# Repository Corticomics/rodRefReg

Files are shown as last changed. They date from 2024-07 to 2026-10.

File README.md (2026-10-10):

# Rodent Refreshment Regulator (RRR)

**A Simple Water Delivery System for Laboratory Animal Care**

<p align="center">
  RRR — Rodent Refreshment Regulator
</p>

## What is the Rodent Refreshment Regulator?

<p align="center">
  A drop of water, on time, every time. 16-channel scheduled water delivery for laboratory rodents, built on a Raspberry Pi 5.
</p>

The Rodent Refreshment Regulator (RRR) helps you automatically deliver precise amounts of water to laboratory animals on a schedule. It takes the guesswork out of water delivery and ensures your research animals receive consistent care.

**No programming knowledge needed!** The system has a simple, user-friendly interface designed for laboratory staff with any level of technical experience.

## Why Use the RRR System?

- **Consistent Care**: Delivers precise water amounts every time
- **Time-Saving**: Automates routine water delivery tasks
- **Animal Welfare**: Ensures animals receive proper hydration
- **Research Quality**: Improves consistency in experimental conditions
- **Remote Monitoring**: Sends alerts about system status

## Getting Started: Step-by-Step Guide

### 1. Setting Up Your System

If the system is already installed in your lab, skip to [Using the Application](#2-using-the-application). If you are building a new device from parts, follow the full bench-build runbook in [HARDWARE_SETUP.md](Project/docs/HARDWARE_SETUP.md) before running the software installer below.

**Requirements**: Raspberry Pi running **Raspberry Pi OS Bookworm (64-bit)** with internet access.

#### One-line install (recommended)

Open a terminal on your Raspberry Pi and run:

```bash
curl -fsSL https://raw.githubusercontent.com/Corticomics/rodRefReg/main/bootstrap.sh | bash
```

That command downloads a small bootstrap script, which installs `git`, clones the repository into `~/rodRefReg`, and then runs the full installer non-interactively. The whole process takes ~5–10 minutes on a fresh Pi (sudo password prompted once for apt).

To preview without changing anything:

```bash
curl -fsSL https://raw.githubusercontent.com/Corticomics/rodRefReg/main/bootstrap.sh | bash -s -- --dry-run
```

#### Manual install

If you'd rather audit the code before running it, or you already have the repo cloned:

```bash
git clone https://github.com/Corticomics/rodRefReg.git ~/rodRefReg
cd ~/rodRefReg
./install.sh
``` 
It will:

- Install all system and Python dependencies
- Enable I²C (via `raspi-config`) without requiring a reboot
- Compile and install the Sequent Microsystems 16-relay HAT driver
- Set up a stable `/dev/teensy_flow` symlink for the Teensy flow sensor (via udev)
- Create a desktop icon, an application-menu entry, and a systemd `--user` service for autostart
- Verify every Python import and the relay HAT CLI before exiting

**Useful installer flags** (work after `./install.sh` or after `bash -s --` in the curl form):

| Flag | Purpose |
|---|---|
| `--dry-run` | Print every action without changing anything (safe to try first) |
| `-y` / `--yes` | Non-interactive mode |
| `--only <module>` | Run a single stage, e.g. `--only 40-hardware` |
| `--skip <module>` | Skip a stage, repeatable |
| `--branch <name>` | Install from a non-`main` branch |
| `--help` | Full usage |

**After install**: log out and back in once (so the new `i2c`, `gpio`, `dialout` group memberships apply), then launch via the desktop icon or `~/.local/bin/rrr`. Reboot only if you want the `consoleblank=0` boot setting to take effect.

Logs from every install run live under `~/.local/state/rrr/install-<timestamp>.log`.

## Documentation

This README is the entry point. Topic-specific runbooks live in
[`Project/docs/`](Project/docs/); each is linked once below so this file stays the single
table of contents you need to bookmark.

| Document | When to read it |
|---|---|
| [HARDWARE_SETUP.md](Project/docs/HARDWARE_SETUP.md) | Building a device from parts: Pi, relay HAT, valves, power, common ground, tubing, wall mount. Read this first for any new install. |
| [16-RELAYS Vendor Manual (PDF)](Project/docs/16-RELAYS-UsersGuide_d5e24457-bdd9-4e16-a307-7f90bbd668bb.pdf) | Authoritative reference for the Sequent Microsystems relay HAT (jumpers, stack levels, I²C addresses). |
| [QUICK_REFERENCE.md](QUICK_REFERENCE.md) | Day-to-day operator cheatsheet (animals, schedules, cages, shortcuts). |
| [CALIBRATION_QUICK_START.md](Project/docs/CALIBRATION_QUICK_START.md) | Calibrating a valve in about 10 minutes with the in-app wizard. |
| [VALVE_CALIBRATION_GUIDE.md](Project/docs/VALVE_CALIBRATION_GUIDE.md) | Technical reference behind the calibration wizard (algorithm, schema, API). |
| [PRIMING_FEATURE_DOCUMENTATION.md](Project/docs/PRIMING_FEATURE_DOCUMENTATION.md) | Priming control architecture and safety interlocks. |
| [TOPOLOGY_VALIDATION.md](Project/docs/TOPOLOGY_VALIDATION.md) | Proving an independent (one syringe per animal) rig against the manifold rig: pre-declared criteria C1–C9, bench recipe, and the tools that grade the weighings. |
| [DEVELOPMENT.md](Project/docs/DEVELOPMENT.md) | Software architecture, modules, data flow, and dev-environment setup. |
| [DATABASE.md](Project/docs/DATABASE.md) / [DATABASE_ARCHITECTURE.md](Project/docs/DATABASE_ARCHITECTURE.md) | SQLite schema, ERD, and `DatabaseHandler` reference. |
| [STOP_AND_PARTIAL_DELIVERY.md](Project/docs/STOP_AND_PARTIAL_DELIVERY.md) | Design of v2.0.0's Stop, CLOSE ALL RELAYS availability, run history and the Animals tab's last-run column (for maintainers). |
| [MAINTENANCE.md](Project/docs/MAINTENANCE.md) | Release, versioning (SemVer for RRR), tagging, and recovery procedures. |
| [UPDATE_SYSTEM.md](Project/docs/UPDATE_SYSTEM.md) | Full design of the in-app update pipeline (bundle format, blue-green layout, boot sentinel). |
| [CLAUDE.md](CLAUDE.md) | One-page hard-rules summary for maintainers and AI assistants. |
| [STL Files](Project/docs/STL%20Files/) | 3D-printable reservoir mounts, intra-cage water collectors, pump holders. |
---

### 2. Using the Application

#### First-Time Login

1. Start the RRR application by clicking the desktop icon or running `~/.local/bin/rrr`
2. You'll see a login screen - if you don't have an account, click "Create Account" to continue
3. The main screen will appear with several tabs

#### Adding Your Animals

1. Go to the **Animals** tab
2. Click **Add Animal**
3. Enter the animal's information as requested
4. Click **Save**
5. Repeat for each animal

#### Naming Cages

1. Go to the **Cages** tab to see a visual layout of the relay board
2. Double-click any cage tile, type a custom name (e.g., "Rack A — Cage 3") and press Enter
3. Names sync automatically to the Wizard, Schedules, and Calibration views

#### Creating a Water Delivery Schedule

The **Schedule Wizard** walks you through schedule creation in 4 steps:

1. Go to the **Wizard** tab (or click **+ New Schedule** in the Schedules hub)
2. **Step 1 — Type**: Choose between:
   - **Instant Delivery**: All animals receive their volume at the same time; conflicting times are auto-queued
   - **Staggered Delivery**: The total volume is divided uniformly across the selected time window
3. **Step 2 — Animals**: Multi-select the animals/cages to include (limited by your hardware: 15 cages on the first HAT, because relay 16 is the master valve or, on an independent rig, reserved and unwired; 16 on each further HAT)
4. **Step 3 — Parameters**: Set per-animal volume, time window, and schedule name
5. **Step 4 — Review**: Confirm the configuration and click **Save Schedule**

The new schedule appears as a card in the **Schedules** hub.

#### Managing Schedules

- The **Schedules** tab is a hub that shows every schedule as a card with a search bar and multi-select for bulk delete
- Click **Edit** on any card to reopen the wizard-style editor
- Click **Info** for full schedule details

#### Starting Water Delivery

1. In the **Schedules** hub, drag a schedule card onto the **Run/Stop** drop area on the right
2. Click **Run**. In solenoid pulse mode (the default), Run refuses a schedule that waters a cage with no usable calibration measured under this device's valve topology: it shows *Valve calibration needed* with the cages to calibrate, and the schedule does not start
3. The **Execution Monitor** tab appears next to the Terminal and shows live per-cage progress
4. Monitor the terminal output or the Execution Monitor cards for real-time updates

#### Stopping the Program

1. Click **Stop** to halt water delivery
2. RRR closes every relay. If a relay HAT does not confirm, it shows **Relays Not Confirmed Off**: a valve may still be open, so disconnect the valve power supply, then check the relay HAT and its I²C connection

#### Unattended Operation

The RRR system is designed to run continuously even when you disconnect your display, keyboard, or mouse. For long-term experiments:

1. **Autostart on graphical login** — enable the user-level systemd service (do **not** run this as root):
   ```bash
   systemctl --user daemon-reload
   systemctl --user enable --now rrr.service
   ```

2. **Headless / no graphical login** — also enable user lingering so the service starts at boot:
   ```bash
   sudo loginctl enable-linger "$USER"
   ```

3. **Power management**: the installer adds `consoleblank=0` to `/boot/firmware/cmdline.txt` so the console will not blank during experiments. A reboot applies this.

4. **Status & logs**:
   ```bash
   systemctl --user status rrr.service
   journalctl --user -u rrr.service -f
   ```

5. **Stop / disable**:
   ```bash
   systemctl --user disable --now rrr.service
   ```

## Daily Use Guide

### Routine

1. **Check System Status**: Open the RRR application and verify it's running/Ran correctly
2. **Update Animal Weights**: Record new animal weights in the Animals tab
3. **Inspect Water Lines**: Check for any leaks or blockages
4. **Water Reservoir**: Ensure the water reservoir has sufficient clean water. On an independent rig (one syringe per animal), check every syringe line daily; a primed line holds about three days, so prime again (Settings → Priming) any line left idle over a long weekend

5. **Check Delivery Log**: Review the delivery history in the terminal
6. **Verify Schedules**: Confirm schedules for the next day
7. **Backup Data** (optional): Export/Import animal data if needed

## Common Questions

### What if the system isn't delivering water?

1. Check that **Run** has been clicked and the schedule started: if Run showed *Valve calibration needed* or *Cage not on this device*, calibrate the listed cages in **Settings → Calibration** (or edit the schedule) and press **Run** again
2. Verify that your time window is correct: a schedule whose end time has passed shows *Expired Schedule* and does not start; if only the start time has passed, RRR asks whether to run the rest of the window
3. Inspect the water tubes for air bubbles or blockages (make sure to prime the tubes and pumpos prior to first use)
4. Check that the water reservoir has enough water
5. Look in the Terminal tab for `[VALVE ERROR]`: the line says why that delivery stopped, most often a valve command that did not reach its relay HAT. Check the HAT (`sudo i2cdetect -y 1`); after fixing a HAT that was missing when RRR started, close and reopen RRR

### How do I know how much water each animal received?

You can watch each delivery in the Terminal tab. Every delivery is also written to the `dispensing_history` table (the delivery ledger): the dose asked for, the volume dispensed and its status. On the device, `cd ~/rrr/current/Project && ~/rrr/shared/venv/bin/python3 tools/gravimetric_check.py daily --since YYYY-MM-DD` prints each day's totals per cage.

### What if I need to change a schedule mid-experiment?

You can create a new schedule at any time. Stop the current program, create your new schedule, and start the program again with the new settings.

### How do I calibrate the system for accurate water delivery?

Go to **Settings → Calibration**. The table lists every cage, with the custom names you set in the Cages tab. Click **Calibrate** on a cage's row, or **Calibrate All Uncalibrated** to go through every cage that has no calibration yet, one marked **Invalid** (its volume per pulse or pulse width is missing, zero or invalid), or one marked **Stale** (measured under the other valve topology; one saved before v1.21.0 counts as shared manifold). Set the valve topology (**Settings → Delivery → Valve Topology**) before calibrating. For each cage the wizard:

1. Walks you through a pre-flight checklist (prime the tubing in the **Priming** sub-tab first if it holds air)
2. Fires a fixed number of pulses into a beaker at the pulse width and interval you set
3. Asks for the volume you weighed
4. Saves that cage's mL per pulse, with the valve topology it was measured under; every later delivery to the cage uses it. In solenoid pulse mode (the default), **Run** refuses a schedule that waters a cage with no calibration, an Invalid one or a Stale one

Calibrate before starting a new experiment and periodically to maintain accuracy. The **Priming** sub-tab in Settings can be used on its own any time you swap tubing, refill the reservoir or, on an independent rig, refill or replace a syringe. It is refused while a schedule or a calibration is running. Changing the valve topology restarts RRR, and Priming then shows the controls for the new topology; if RRR cannot restart itself, Priming cannot open a valve until RRR is closed and reopened.

### How do I resolve "i2c-1 not found" or other I²C errors?

The installer enables I²C automatically via `raspi-config nonint do_i2c 0`, which makes `/dev/i2c-1` (the GPIO HAT bus) appear without a reboot on every Pi 4 and Pi 5. If the relay HAT does not respond:

1. Confirm the bus is up:
   ```bash
   ls /dev/i2c-*           # /dev/i2c-1 must be in the list
   sudo i2cdetect -y 1     # the HAT should appear at its I²C address
   ```

2. If `/dev/i2c-1` is missing, re-run the hardware module of the installer (idempotent, ~5 s):
   ```bash
   cd ~/rodRefReg
   ./install.sh -y --only 40-hardware
   ```

3. If it is still missing, run the standalone helper and reboot:
   ```bash
   ~/rodRefReg/scripts/runtime/fix_i2c.sh
   sudo reboot
   ```

4. As a last resort, enable I²C interactively:
   ```bash
   sudo raspi-config       # → Interface Options → I2C → Enable
   ```

Different Raspberry Pi models expose different *internal* I²C bus numbers (Pi 5 also shows `/dev/i2c-13` and `/dev/i2c-14`), but the relay HAT always sits on bus 1.

### How can I run a Python script against the RRR install?

The application uses a virtual environment at `~/rrr/shared/venv`, and the running release lives in `~/rrr/current`. Always call that Python directly — do **not** rely on the system `python3`, which (on Bookworm) is intentionally locked down by PEP 668:

```bash
cd ~/rrr/current/Project
~/rrr/shared/venv/bin/python3 tools/gravimetric_check.py list
```

That example only reads the delivery ledger. Do **not** run `tests/test_relay_hat.py` on a plumbed rig: without arguments it switches every relay on, which opens every valve.

## Getting Help

If you need assistance with the RRR system:

1. Click the **Help** tab in the application for detailed guides
2. Use the search bar to find specific help topics
3. Contact your laboratory manager or IT support
4. For urgent issues, contact [zepaulojr2@gmail.com](mailto:zepaulojr2@gmail.com)

## Important Safety Notes

- Always monitor the system during the first few days of a new setup
- Check animals regularly to ensure they are receiving adequate hydration and to check if the hardware setup was made correctly do not leave the subjects by themselves for the first few uses to ensure correct software and hardware setup and safety 
- Keep water lines and pumps clean to prevent contamination
- Never modify the hardware without consulting technical staff

---

**Remember**: The RRR system is designed to assist with animal care, not replace regular monitoring. Always follow your institution's animal welfare guidelines and protocols.

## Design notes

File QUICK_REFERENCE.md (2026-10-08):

# Rodent Refreshment Regulator - Quick Reference Guide

This quick reference guide covers the most common tasks and troubleshooting tips for the Rodent Refreshment Regulator (RRR) system. For more detailed information, refer to the in-app Help tab.

## Common Tasks

### Animal Management

| Task | How To Do It |
|---|---|
| Add a new animal | Animals tab → Add Animal → Fill details → Save |
| Edit animal info | Animals tab → Select animal → Edit → Update details → Save |
| Update weight | Animals tab → Select animal → Edit → Enter new weight → Save |
| Remove animal | Animals tab → Select animal → Delete → Confirm |

### Schedule Management

| Task | How To Do It |
|---|---|
| Create schedule | Wizard tab (or "+ New Schedule" in Schedules hub) → Step 1–4 → Save |
| Edit schedule | Schedules tab → card menu → Edit → Update → Save |
| Delete schedule | Schedules tab → card menu → Delete (or multi-select → bulk delete) |
| Assign animals to cages | Inside the Wizard, Step 2 — multi-select from the available list |
| View schedule details | Schedules tab → card **Info** button |

### Cage Management

| Task | How To Do It |
|---|---|
| Rename a cage | Cages tab → double-click the cage tile → type the name → Enter (Esc cancels; relay 16 cannot be renamed) |
| View relay layout | Cages tab — shows the full HAT board: relay 16 is the MASTER SOLENOID on a shared-manifold rig and RESERVED (unused) on an independent rig |

### System Operations

| Task | How To Do It |
|---|---|
| Start water delivery | Drag schedule card onto Run/Stop drop area → **Run**. In solenoid pulse mode (the default), Run refuses a schedule that waters a cage with no usable calibration measured under this device's valve topology (*Valve calibration needed*): calibrate the listed cages first |
| Stop water delivery | **Stop**. If it shows *Relays Not Confirmed Off*, disconnect the valve power supply, then check the relay HAT and its I²C connection |
| Monitor a live run | Execution Monitor tab appears next to Terminal during a run |
| Test a valve | Settings → Priming → select the cage → **Open Selected**, then **Close Selected** (on a shared-manifold rig click **Open Master** first and **Close Master** after) |
| Calibrate valves | Settings → Calibration → **Calibrate** on the cage's row (or **Calibrate All Uncalibrated**) |
| Prime tubing | Settings → Priming → select cage → **Open Selected** → **Close Selected** once water flows (on a shared-manifold rig click **Open Master** first and **Close Master** after) |
| Change valve topology | Settings → Delivery → Valve Topology (logged in; refused while a schedule, priming or calibration runs). Confirm with **Restart RRR**: RRR restarts on the new topology. Log in again, then recalibrate the cages marked Stale |
| Set up notifications | Settings → General → Slack Integration → enter the Slack Bot Token and Channel ID (each is saved when you press Enter or leave the field, and is used from the next message) |

## Troubleshooting Guide

### Water Delivery Issues

| Problem | Solution |
|---|---|
| No water delivered | • Check if the schedule is running (Run may have refused it: *Valve calibration needed* lists the cages to calibrate)<br>• Ensure time window is correct<br>• Look in the Terminal tab for `[VALVE ERROR]`: the line says why the delivery stopped, most often a valve command that did not reach its relay HAT<br>• Check the water reservoir level, or on an independent rig that animal's syringe and line<br>• Verify pump connections (pump mode) |
| Uneven water delivery | • Check for air bubbles in tubing: prime the line (Settings → Priming)<br>• Solenoid rig: recalibrate that cage (Settings → Calibration → **Recalibrate** on its row)<br>• Pump mode: calibrate the pumps and run 200 test triggers to prime them |
| Leaking connections | • Check tube fittings<br>• Replace damaged tubing<br>• Ensure correct tube diameter (2mm) |

### Software Issues

| Problem | Solution |
|---|---|
| Application won't start | • Restart your Raspberry Pi<br>• Run `~/.local/bin/rrr` from a terminal to see error messages (where RRR runs as the user service: `journalctl --user -u rrr.service -n 50`) |
| Can't save settings | • Log in with a user account (not guest mode)<br>• Check file permissions |
| Slack notifications not working | • Verify internet connection<br>• Check Slack credentials<br>• Ensure channel ID is correct |

### Hardware Issues

| Problem | Solution |
|---|---|
| Relay HAT not detected | • Check physical connections and `sudo i2cdetect -y 1`<br>• Verify the stack-level jumpers<br>• After fixing it, close and reopen RRR: until then every valve delivery to a missing HAT fails with `[VALVE ERROR]` |
| `[VALVE CRITICAL] … OPEN`, *Emergency Stop Failed* or *Relays Not Confirmed Off* | • Disconnect the valve power supply first<br>• Then check the relay HAT and its I²C connection; Settings → Priming → CLOSE ALL RELAYS switches every relay off again and stops a running schedule (it does not resume: Run starts it over, so check what each animal has received first)<br>• `[VALVE OK] … closed after all` means a later close got through and that alarm is cleared |
| Pump not triggering | • Test the relay<br>• Check power connections<br>• Verify common ground connection |
| System freezes during operation | • Check for overheating<br>• Ensure power supply is adequate<br>• Reduce number of simultaneous triggers |

## Keyboard Shortcuts

| Shortcut | Action |
|---|---|
| `Ctrl+F` or `F3` | Help tab: jump to the search bar |
| `Ctrl+Tab` | Switch between tabs |
| `Esc` | Close popup dialogs; in the Help tab clear the search; in the Cages tab cancel a rename |

Run and Stop have no keyboard shortcut: use the **Run** and **Stop** buttons.

## Daily Checklist

### Morning Setup
- [ ] Check water reservoir level (on an independent rig, every animal's syringe) and refill if needed
- [ ] Inspect tubing for leaks or blockages; on an independent rig check every syringe line daily; a primed line holds about three days, so prime again any line left idle over a long weekend
- [ ] Update animal weights
- [ ] Verify schedule for the day
- [ ] Start the program

### Evening Closeout
- [ ] Review water delivery logs
- [ ] Check animal hydration status
- [ ] Clean any soiled tubing
- [ ] Prepare schedule for next day if needed

## Contact Information

For technical support, contact:
- Lab Tech: [Jose Paulo](mailto:josepaulo.pereirajun@ucalgary.ca)

For application issues, report through the Help tab in the application.

---

**Remember**: The Help tab in the application provides more detailed information on all features. Use the search function to quickly find specific topics.

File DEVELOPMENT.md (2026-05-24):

# Rodent Refreshment Regulator - Development Guide

This document provides technical information for developers who want to understand or contribute to the Rodent Refreshment Regulator (RRR) project. It covers the architecture, code organization, data flow, and contribution guidelines.

> **Database schema, ERD, and `DatabaseHandler` method reference:** see
> [`docs/DATABASE.md`](docs/DATABASE.md). **Update system / release pipeline:** see
> [`docs/UPDATE_SYSTEM.md`](docs/UPDATE_SYSTEM.md).

## Table of Contents
- [Architecture Overview](#architecture-overview)
- [Code Organization](#code-organization)
- [Data Flow](#data-flow)
- [Hardware Interaction](#hardware-interaction)
- [User Interface](#user-interface)
- [Authentication System](#authentication-system)
- [Scheduling System](#scheduling-system)
- [Notification System](#notification-system)
- [Logging System](#logging-system)
- [Development Environment Setup](#development-environment-setup)
- [Testing Guidelines](#testing-guidelines)
- [Contribution Guidelines](#contribution-guidelines)

## Architecture Overview

The RRR follows the Model-View-Controller (MVC) architecture pattern:

- **Model**: Manages data, logic, and rules of the application.
- **View**: Handles the user interface components using PyQt5.
- **Controller**: Processes user inputs and updates both the model and view accordingly.

### Key Components:

```
┌─────────────────┐     ┌─────────────────┐     ┌─────────────────┐
│      View       │     │    Controller   │     │      Model      │
│  (PyQt5 UI)     │◄───►│ (Input Handler) │◄───►│  (Data & Logic) │
└─────────────────┘     └─────────────────┘     └─────────────────┘
        ▲                       ▲                       ▲
        │                       │                       │
        ▼                       ▼                       ▼
┌─────────────────┐     ┌─────────────────┐     ┌─────────────────┐
│   User Input    │     │Hardware Control │     │   Database      │
│                 │     │ (GPIO & Relays) │     │                 │
└─────────────────┘     └─────────────────┘     └─────────────────┘
```

## Code Organization

The project is structured as follows:

```
rodent-refreshment-regulator/
├── README.md                # User documentation
├── DEVELOPMENT.md           # Developer documentation
├── installer/               # Installation scripts and utilities
│   ├── main.py              # Installer entry point
│   ├── ui/                  # Installer UI components
│   ├── utils/               # Installer utility functions  
│   └── requirements.txt     # Python dependencies for installer
├── Project/                 # Main application code
│   ├── main.py              # Application entry point (boots Qt, lazy hardware init)
│   ├── settings.json        # Configuration file
│   ├── rrr_database.db      # SQLite database
│   ├── models/              # Data models
│   │   ├── animal.py
│   │   ├── Schedule.py
│   │   ├── cage.py          # Cage entity (custom names, relay mapping)
│   │   ├── database_handler.py
│   │   ├── login_system.py
│   │   ├── relay_unit.py
│   │   └── relay_unit_manager.py
│   ├── ui/                  # PyQt5 widgets and tabs
│   │   ├── gui.py                       # RodentRefreshmentGUI main window
│   │   ├── splash_screen.py             # Splash on startup
│   │   ├── login_gate_widget.py         # Gates content behind login
│   │   ├── projects_section.py          # Container for Schedules/Animals/Wizard/Cages
│   │   ├── schedules_hub.py             # Schedule cards grid (replaces drag-drop tab)
│   │   ├── schedule_wizard.py           # 4-step schedule creation wizard
│   │   ├── wizard_tab.py                # Wizard tab host
│   │   ├── animals_tab.py
│   │   ├── cages_visualization_tab.py   # Visual relay-board layout
│   │   ├── cage_manager_widget.py
│   │   ├── SettingsTab.py               # Delivery / Calibration / Priming / General
│   │   ├── CalibrationWizard.py         # Per-cage calibration flow
│   │   ├── PrimingControlWidget.py
│   │   ├── ScheduleProgressTracker.py   # Execution Monitor (live cards)
│   │   ├── run_stop_section.py
│   │   ├── UserTab.py
│   │   ├── HelpTab.py
│   │   ├── terminal_output.py
│   │   ├── components/, widgets/, style/, src/
│   │   └── [additional UI components]
│   ├── controllers/         # Business logic
│   │   ├── system_controller.py
│   │   ├── pump_controller.py
│   │   ├── projects_controller.py
│   │   ├── schedule_controller.py
│   │   ├── delivery_queue_controller.py
│   │   └── WateringController.py
│   ├── gpio/                # Hardware control
│   │   ├── gpio_handler.py
│   │   ├── relay_worker.py              # Worker thread; lazy hardware init
│   │   └── mock_gpio_handler.py
│   ├── strategies/          # Delivery strategies
│   │   ├── solenoid_flow_strategy.py    # Solenoid + flow sensor
│   │   └── (peristaltic legacy)
│   ├── drivers/             # Hardware drivers
│   │   └── uart_flow_sensor.py          # Teensy 4.1 UART bridge
│   ├── teensy_flow_reader/  # Teensy sketch + helper
│   ├── ir_module/           # Optional IR drinking-detection extension
│   ├── utils/, notifications/, settings/, saved_settings/, migrations/
│   ├── tests/
│   └── docs/                # Project-level developer docs
├── docs/                    # Repo-level docs (SOP, FAQ)
└── STL Files/               # 3D printing files
```

## Data Flow

The application's data flows through several key paths:

### 1. Configuration Flow

```
User Input → Controller → Model → Config File → Controller → Hardware
```

1. User inputs settings via the GUI
2. Controller processes and validates inputs
3. Model stores configuration
4. Configuration is saved to disk
5. Controller applies settings to hardware

### 2. Scheduling Flow

```
Schedule Model → Schedule Controller → Hardware Controller → Relay HAT → Pumps
```

1. Schedule model stores delivery timing and volume data
2. Schedule controller determines when to trigger deliveries
3. Hardware controller receives trigger commands
4. Commands are sent to relay HATs
5. Relays activate pumps to deliver water

### 3. Notification Flow

```
Hardware Event → Controller → Notification System → External Service
```

1. Hardware events (triggers, errors) are detected
2. Controller processes events
3. Notification system formats messages
4. Messages are sent to email/Slack services

### 4. Logging Flow

```
System Events → Logger → Terminal Display + Log Files
```

1. Events throughout the system are captured
2. Logger processes and formats messages
3. Messages are displayed in the terminal UI
4. Messages are also written to log files

## Hardware Interaction

The hardware control system interfaces with Sequent Microsystems Relay HATs using the GPIO pins on the Raspberry Pi.

### Key Classes:

- `gpio_handler.py`: Manages all hardware interactions through `RelayHandler` class
- `relay_worker.py`: Worker thread for asynchronous hardware operations
- `RelayUnitManager`: Manages relay units configuration
- `relay_unit.py`: Represents a relay unit and its operations

### HAT Communication:

The system uses Sequent Microsystems' library to communicate with the HATs. The `RelayHandler` class provides methods for:

- Initializing HATs based on their stack level
- Sending trigger commands to specific relays
- Reading HAT status
- Error detection and recovery

### Safety Mechanisms:

- Stagger timing between triggers to prevent power surges
- Validation of HAT addresses before operations
- Error handling for failed triggers
- Maximum daily water limits

## User Interface

The UI is built with PyQt5 and uses a tab-based organization with a login gate.

### Main Components:

- `gui.py` — `RodentRefreshmentGUI` main window; hosts the tabbed Projects section and the Run/Stop section
- `login_gate_widget.py` — gates the Projects content behind authentication
- `projects_section.py` — container for the **Schedules**, **Animals**, **Wizard**, **Cages** tabs
- `schedules_hub.py` — Schedules tab; grid of schedule cards with search, multi-select, edit, drag-to-run
- `schedule_wizard.py` + `wizard_tab.py` — 4-step schedule creation wizard (Type → Animals → Parameters → Review)
- `cages_visualization_tab.py` + `cage_manager_widget.py` — visual relay-board layout, cage naming
- `SettingsTab.py` — sub-tabs: **Delivery**, **Calibration**, **Priming**, **General**
- `CalibrationWizard.py` — per-cage calibration flow, launched from Settings → Calibration
- `PrimingControlWidget.py` — prime tubing / valves
- `ScheduleProgressTracker.py` — Execution Monitor with live per-cage cards (appears as a second tab next to the Terminal during a run)
- `run_stop_section.py` — Run/Stop controls (gated by `login_system`)
- `terminal_output.py`, `HelpTab.py`, `UserTab.py`

### Cross-tab Synchronization:

Cage renaming uses an observer pattern: `CagesVisualizationTab.cage_names_updated` →
`SettingsTab.refresh_calibration_table`. The same names are read by the
Wizard via `database_handler.get_cages_for_dropdown()`.

### Lazy Hardware Initialization:

Hardware (`RelayHandler`, flow sensor) is instantiated on a `QThread` worker inside
`gpio/relay_worker.py` to keep the UI responsive. The Run/Stop section connects
to worker signals; signal connections are reset between consecutive schedule runs
(see `run_stop_section.py` and commit `4c99f5a`).

### UI Data Binding:

The UI components connect to controllers using PyQt5's signal-slot mechanism:

```python
# Example of signal-slot connection
self.runButton.clicked.connect(self.controller.start_schedule)
self.settingsForm.valueChanged.connect(self.controller.update_settings)
```

## Authentication System

The authentication system allows different access levels based on user roles.

### Key Features:

- User registration and login
- Role-based permissions (Administrator, Technician, Observer)
- Password security with salted hashing
- Session management
- Guest mode with limited functionality

### Data Flow:

1. User enters credentials
2. Authentication controller validates credentials
3. User model is updated with permissions
4. UI elements are enabled/disabled based on permissions

## Scheduling System

The scheduling system manages when water is delivered to each animal.

### Components:

- `models/Schedule.py` — schedule data structure (per-animal volumes, windows, mode)
- `controllers/schedule_controller.py` — runs schedules
- `controllers/delivery_queue_controller.py` — queues and orders pulses
- `controllers/WateringController.py` — orchestrates a single delivery pulse
- `strategies/solenoid_flow_strategy.py` — closed-loop solenoid delivery using flow-sensor feedback

### Delivery Modes:

1. **Instant** — animals receive their target volume at one or more specific times; conflicts auto-queue
2. **Staggered** — total target volume is divided uniformly across a user-defined time window
3. **Time-window guard** — `ScheduleController` validates the active window before each pulse
4. **Per-valve calibration** — calibration factors per cage stored in the DB and applied at runtime

## Notification System

The notification system alerts users to important events.

### Supported Methods:

- **Slack Notifications**: Using Slack's API through the slack_sdk

### Implementation:

```python
# Slack notification example (from notifications.py)
def send_slack_notification(self, message):
    if not self.slack_token or not self.channel_id:
        print("Slack credentials not set, skipping notification")
        return False
    
    try:
        response = self.client.chat_postMessage(
            channel=self.channel_id,
            text=message
        )
        return response["ok"]
    except Exception as e:
        print(f"Error sending Slack notification: {e}")
        return False
```

## Logging System

The logging system records system events for monitoring and debugging.

### Log Levels:

- `DEBUG`: Detailed information for debugging
- `INFO`: General information about system operation
- `WARNING`: Issues that don't prevent operation
- `ERROR`: Problems that prevent specific functions
- `CRITICAL`: System-wide failures

### Implementation:

The application uses stream redirection to capture output and display it in the UI terminal:

```python
# StreamRedirector from main.py
class StreamRedirector(QObject):
    message_signal = pyqtSignal(str)
    def __init__(self):
        super().__init__()
    def write(self, message):
        if message.strip():
            self.message_signal.emit(message)
    def flush(self):
        pass
```

## Development Environment Setup

### Prerequisites:

- Python 3.6+
- PyQt5
- Raspberry Pi (for hardware testing)
- Sequent Microsystems Relay HATs (for hardware testing)

### Setup Steps:

1. **Clone the repository**:
   ```sh
   git clone https://github.com/yourusername/rodent-refreshment-regulator.git
   cd rodent-refreshment-regulator
   ```

2. **Create a virtual environment**:
   ```sh
   python -m venv venv
   source venv/bin/activate  # On Windows: venv\Scripts\activate
   ```

3. **Install dependencies**:
   ```sh
   pip install -r installer/requirements.txt
   ```

4. **Run the installer** (if setting up for the first time):
   ```sh
   cd installer
   python main.py
   ```

5. **Run the application** (after installation):
   ```sh
   cd Project
   python main.py
   ```

### Running in Development Mode:

You can run the application with various test files for debugging hardware:

```sh
python test_relay_connection.py  # Test basic relay connectivity
python test_relay_diagnostic.py  # Run diagnostics
```

### Mock Hardware:

For development without physical hardware, use the mock hardware module by modifying the `gpio_handler.py` to use `mock_gpio_handler.py`.

## Testing Guidelines

For testing the RRR, focus on the following areas:

- **Unit Tests**: Test individual components such as schedule validation
- **Integration Tests**: Test component interactions like controller-model communication
- **UI Tests**: Test UI functionality using pytest-qt
- **Hardware Tests**: Use the provided test scripts for hardware interaction

### Writing Tests:

```python
# Example test approach for schedule validation
def test_schedule_validation():
    # Setup
    schedule = Schedule(name="Test Schedule", interval=60, triggers=2, window_start=8, window_end=20)
    
    # Test valid input
    assert schedule.is_valid() == True
    
    # Test invalid input
    schedule.interval = -10
    assert schedule.is_valid() == False
```

## Contribution Guidelines

> **Releasing a change?** See [MAINTENANCE.md](MAINTENANCE.md) for the
> full recipe — when to cut a release, how to pick the SemVer bump,
> tagging procedure, CI verification, and recovery from a bad release.
> The section below is the short version for any PR.

### Submitting Changes:

1. Fork the repository
2. Create a new branch for your feature (`git checkout -b feature/my-feature`)
3. Make your changes
4. Test your changes with the test scripts provided
5. Commit your changes (`git commit -am 'Add new feature'`)
6. Push to the branch (`git push origin feature/my-feature`)
7. Create a new Pull Request

### Code Style:

- Follow PEP 8 guidelines
- Use meaningful variable and function names
- Include docstrings for all functions, classes, and modules
- Keep functions short and focused on a single task

### Commit Messages:

Follow the conventional commits format:

```
type(scope): description

[optional body]

[optional footer]
```

Types: feat, fix, docs, style, refactor, test, chore

### Hardware Safety Guidelines:

When modifying hardware control code:

1. Never remove safety checks
2. Test extensively without animals before deployment
3. Include detailed comments explaining hardware interactions
4. Document changes to hardware control in both code and documentation

---

Thank you for contributing to the Rodent Refreshment Regulator project. By following these guidelines, you help ensure the reliability and safety of the system for researchers and their animals.

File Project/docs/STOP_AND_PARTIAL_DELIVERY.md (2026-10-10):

# Stop, Partial Delivery and Run History — Design Doc

**Status:** approved 2026-10-09; to be implemented in v2.0.0 (PR train in §12).
Line references are to f36d5223 (v1.21.0) unless stated. Companion to
[PRIMING_FEATURE_DOCUMENTATION.md](PRIMING_FEATURE_DOCUMENTATION.md)
(CLOSE ALL RELAYS), [DATABASE.md](DATABASE.md) (schema) and
[MAINTENANCE.md](MAINTENANCE.md) (releases).

This doc records the v2.0.0 design: Stop becomes the only way to end a
running schedule, every run that starts delivering is recorded per animal,
and the Animals tab shows each animal's last run. It lands before the code,
so the owner and every code PR's reviewers see the contract and the version
decision first. A code PR that refines a contract here updates its section
in the same PR; the docs PR (PR 13) reconciles the rest and sets the Status
line.

---

## 1. Why

The owner's request, with a minimal schema change, existing patterns
reused, and the delivery and Stop hot paths kept simple and cheap (§5):

- **CLOSE ALL RELAYS** is a priming and emergency control: not available
  while a schedule runs.
- **Stop** is fixed, and records the amounts scheduled and delivered.
- **The Animals tab** gains *Last schedule delivered amount*: 1:1 with the
  scheduled amount when a run completes, less when it is stopped early.
- **Incomplete runs are bright red** and show scheduled vs delivered.

---

## 2. Where v1.21.0 stands

| Fact | Ref |
|---|---|
| No run state is saved: nothing writes `schedules.dispensing_status`, and `update_schedule_status` updates a `status` column that does not exist and has no callers | `database_handler.py:update_schedule_status:1036` |
| A run lives only in memory: `RunStopSection.job_in_progress`, the SCHEDULE lock, `main.worker` / `main.thread` | `run_stop_section.py:run_program:264`, `main.py:run_program:216` |
| Every Run starts from zero (`delivered_volumes = {}`): run again after a Stop, a staggered schedule gives its whole dose again and an instant one skips the passed times | `main.py:run_program:325`, `relay_worker.py:115`, `run_instant_cycle:496-527` |
| Every ending emits the same `worker.finished`: a natural end, the circuit breaker, an error or Stop | `relay_worker.py:check_completion:1219`, `stop:1498` |
| Each attempt credits what it dispensed to `delivered_volumes` and writes one ledger row with `volume_actual_ml`. Credit is pulses × the cage's calibration (sensor-blended when fitted; triggers × volume in pump mode); nothing reads a relay back | `relay_worker.py:_finalize_delivery:997`, `database_handler.py:log_delivery:1733`, `gpio_handler.py:set_all_relays:196` |
| The ledger has no run id, its `timestamp` is the planned time, and re-runs share one `schedule_id` | `database_handler.py:create_tables:39` |
| Instant runs get no `relay_unit_assignments`, so their completion tolerance falls back to 0.01 mL | `main.py:241`, `relay_worker.py:_completion_tolerance_ml:1115-1161` |
| Stop: all-off, then the Stopping dialog (it pumps events), then cancel and teardown; only the first all-off decides "confirmed" | `stop_sequence.py:execute_stop_sequence:148-152` |
| `reset_ui` always releases SCHEDULE; unconfirmed relays give two dialogs (**Relays Not Confirmed Off**, then **Warning**), an abandoned worker none | `run_stop_section.py:reset_ui:711`, `_execute_stop:683-689`; `main.py:_warn_relays_not_confirmed_off:496` |
| The manifold prime opens the master with no cancel check; Run after an abandoned Stop drops a running QThread's only reference | `solenoid_flow_strategy.py:_deliver_pulse_mode:1125`; `main.py:run_program:302-312` |
| Since #177 CLOSE ALL RELAYS stops a running schedule, switches the relays off again, latches EMERGENCY when unconfirmed and builds a fresh handler. It is never greyed; a cage change re-enables Close Selected. The `[VALVE CRITICAL]` alarms say it "stops the schedule" | `PrimingControlWidget.py:_on_emergency_stop_clicked:685`, `:1004`; `SettingsTab.py:_stop_running_schedule:1661`; `solenoid_flow_strategy.py:_alarm_unclosed:720-722`, `gpio_handler.py:_switch_unit_off:361-364` |
| `job_in_progress` is set after `try_acquire(SCHEDULE)` | `run_stop_section.py:run_program:300, :311` |
| Stop needs a login, logout is allowed mid-run and Settings is hidden from guests: after a logout nothing can stop the run | `run_stop_section.py:update_button_states:233`; `gui.py:on_logout:642`, `_update_tab_access:761` |
| The Animals tab hard-codes 7 columns (`setColumnCount(7)`, two `range(7)`, `COLUMN_WIDTHS`), widens columns 5–6 above 800 px, and its filter calls `item.text()` on every cell. `setBackground()` on an item is not painted under the app QSS | `animals_tab.py:61, :77, :142, :213, :259, :443`; `app-light.qss:331` |

---

## 3. Decisions

The owner's answers of 2026-10-09 to the approved plan's 13 questions,
verbatim apart from typo fixes, and the decisions D1–D12 the PRs implement:

| Q | Question | Answer | Decision |
|---|---|---|---|
| 1 | On completion, show the scheduled amount 1:1, the credited figure in the tooltip? | "yes or should we show the amount planned based on the calibration of each cage (use best practices here)" | **D1.** Three figures per animal per run (below); the cell shows delivered, the tooltip all three |
| 2 | Red when short by more than the worker's whole-pulse tolerance? | "yes" | **D2.** The per-animal outcome (below); raw delivered is never compared with scheduled |
| 3 | Red also when a run ends short without Stop, or after a crash? | "yes" | **D2.** `stopped`, `incomplete` and `interrupted` are red |
| 4 | Stop without a login, or block logout? | "logout blocked during run" | **D3.** Log Out greyed and refused during a run (§7) |
| 5 | Last schedule = the latest run that started delivering? | "yes" | **D4.** A re-run replaces it at its first delivery; the history keeps every run |
| 6 | No resume: Run starts over, after a warning? | "yes after a schedule is stopped nothing can be done to get the remaining volume besides creating a new schedule that delivers specifically that remaining volume" | **D5.** No resume; **Last Run Ended Early** asks, and gives the remainder for a new schedule (§9) |
| 7 | Instant run started late: plan what is due, or the whole schedule? | "whole schedule with a warning showing that and asking the user to confirm or cancel" | **D6.** The whole schedule; **Some Deliveries Passed** asks and says the run will show red (§9) |
| 8 | Last run per animal, or every run? | "history table on the database but on the animal table just the last run" | **D7.** Two history tables; no column on `animals`; ledger unchanged (§4) |
| 9 | Keep the run's end time? | "yes" | **D8.** "2 hours ago (YYYY-MM-DD HH:MM)" via `AnimalsTab.calculate_days_ago` (`animals_tab.py:156-177`) |
| 10 | How to show red; export it? | "use frontend best practice, and yes it should" | **D9.** A themed delegate with a status word (§8); the CSV export gains 7 columns |
| 11 | Interrupted: "?" and the delivery log? | "yes" | **D10.** "?" and the `gravimetric_check.py daily` command; no ledger watermark |
| 12 | Version, and order against palette B? | "follow SWE best practices and the maintenance and contributing docs of the project" | **D11.** 2.0.0 (MAJOR), one bump, no `-beta`; palette B is 2.1.0 (§12) |
| 13 | Close Selected also unavailable mid-run? | "yes" | **D12.** Greyed and refused, like CLOSE ALL RELAYS (§7) |

**D1.** **Scheduled** = `requested_ml`; for an instant schedule, the sum
of all its deliveries, past ones included. **Planned** = whole pulses × the
cage's mL per pulse under the rounding policy, per staggered window or per
instant delivery; = scheduled in pump and continuous modes. **Delivered** =
the credited Σ `volume_actual_ml` of the run's ledger rows. A completed run
delivers the plan 1:1 once the planner and the plan share one rounding
rule, an exact half rounding up (PR 6; today's `int(deficit / q + 0.5)`,
`relay_worker.py:888`, misses it in 76 of 6000 surveyed windows, all ties).

**D2.** `completed` when delivered is within RRR's own whole-pulse
tolerance, per mode (§5): staggered, the worker's completion test; instant
in pulse mode, ≥ min(planned − q/2, scheduled − that tolerance); instant in
pump or continuous mode, ≥ planned − 0.01. Otherwise `stopped`,
`incomplete` (short without Stop) or `interrupted` (RRR closed or crashed).
One pulse short of the plan is red, except under nearest rounding at an
exact half-pulse tie or below 0.02 mL per pulse.

---

## 4. Data (PR 5)

The **draft** DDL, reconciled with the merged code by the docs PR; it goes
at the end of `create_tables` (before its commit, `database_handler.py:334`).

```sql
CREATE TABLE IF NOT EXISTS schedule_runs (
    run_id INTEGER PRIMARY KEY AUTOINCREMENT, schedule_id INTEGER NOT NULL,
    schedule_name TEXT NOT NULL, delivery_mode TEXT NOT NULL,      -- 'instant' | 'staggered'
    started_at TEXT NOT NULL, ended_at TEXT, end_reason TEXT,
    started_by INTEGER, stopped_by INTEGER,
    relays_confirmed_off INTEGER, worker_exited INTEGER, app_version TEXT,
    FOREIGN KEY(started_by) REFERENCES trainers(trainer_id),
    FOREIGN KEY(stopped_by) REFERENCES trainers(trainer_id));
CREATE TABLE IF NOT EXISTS schedule_run_animals (
    run_id INTEGER NOT NULL, animal_id INTEGER NOT NULL, relay_unit_id INTEGER,
    requested_ml REAL NOT NULL, planned_ml REAL NOT NULL, delivered_ml REAL,
    outcome TEXT NOT NULL, PRIMARY KEY (run_id, animal_id),
    FOREIGN KEY(run_id) REFERENCES schedule_runs(run_id));
CREATE INDEX IF NOT EXISTS idx_schedule_run_animals_animal_run
    ON schedule_run_animals (animal_id, run_id);
```

- **Values.** `outcome` ∈ {running, completed, stopped, incomplete,
  interrupted}; `end_reason` ∈ {completed, stopped, ended_short,
  interrupted}; Python validates both. No CHECK: a new value would need a
  table rebuild, a one-way migration.
- **Copies, not links:** no foreign key to `schedules`, `animals` or
  `relay_units`, which the history outlives. The declared ones are inert:
  no Project code enables `PRAGMA foreign_keys`, and a migration runner
  that does must re-check deleting a trainer who owns runs. Latest = the
  highest `run_id`, so a clock jump cannot reorder runs.
- **Revert-safe.** Additive, idempotent DDL that older releases never read:
  no `sqlite_master` scan, and the two `SELECT s.*` / `w.*` read other
  tables (`database_handler.py:1072, :1527`). The `animals` columns, the
  ledger and `log_delivery` are unchanged.

**Where the code lives:** `Project/models/schedule_runs_repo.py`
(`RUN_OUTCOMES`, `RUN_END_REASONS`, `LAST_RUN_COLUMNS`, `LAST_RUN_JOIN`,
`last_run_from_row`, `ScheduleRunsRepo(connect)`), behind the facade
below; nothing else leaves `database_handler.py`. CLAUDE.md's R2 trigger 1
fired at its borderline (about 186 code lines); the owner approved the
module (§14, item 14), and PR 5 logs it in
[DATABASE_HANDLER_REFACTOR_DESIGN.md](DATABASE_HANDLER_REFACTOR_DESIGN.md) §11.

| `DatabaseHandler` method | Contract |
|---|---|
| `start_schedule_run(schedule_id, schedule_name, delivery_mode, started_by, animals) -> int \| None` | `animals` = `[{'animal_id', 'relay_unit_id', 'requested_ml', 'planned_ml'}]`; one transaction; None, with nothing written, on an empty list or a DB error |
| `finish_schedule_run(run_id, end_reason, results, stopped_by=None, relays_confirmed_off=None, worker_exited=None) -> bool` | `results = {animal_id: (delivered_ml or None, outcome)}`; True only when this call closed the run; False when it is already closed or unknown, or the DB refused (a lock held over about 5 s); a missing animal is closed `incomplete` with NULL; an unknown value raises ValueError before any write |
| `mark_interrupted_schedule_runs() -> int` | `running` → `interrupted`, `delivered_ml` NULL, `ended_at` = now |
| `get_latest_runs_of_schedule(schedule_id, animal_ids) -> {int: dict}` | each animal's latest run **of this schedule**: the `last_run` keys plus `lab_animal_id`; `{}` on an empty input or a DB error |

**Read path.** `get_all_animals` / `get_animals_by_trainer` gain a LEFT
JOIN on each animal's MAX(`run_id`), still one SELECT. `Animal.last_run`
(dict or None) carries only what the UI reads: `run_id`, `schedule_name`,
`delivery_mode`, `started_at`, `ended_at`, `outcome`, `relay_unit_id`,
`requested_ml`, `planned_ml`, `delivered_ml`; no join on `trainers`.

---

## 5. Recording a run (PR 7)

```
Run click   job_in_progress = True → try_acquire(SCHEDULE) → singleShot(prepare, token)
            ↳ CLOSE ALL RELAYS, Close Selected, Log Out: greyed and refused from here
prepare     token current? → refusals → at most ONE question (§9)
            → calibration gate → main.run_program() → True (thread started) / False
first due   worker thread, _handle_delivery → _open_run_record():
delivery    run_plan built → start_schedule_run() → rows 'running'
end         natural, circuit breaker, error: worker.finished (queued, bound to w)
            → _on_run_finished(w) → _record_run_end(w)   (skipped if stop_reason == 'operator')
            Stop: main.stop_program(): w = worker; w.stop_reason = 'operator';
            execute_stop_sequence() → StopResult → _record_run_end(w, result) + one logs row
close       _record_run_end (GUI thread, once per worker, never raises)
            → finish_schedule_run() → deferred Animals-tab reload
next start  main.setup() / _create_gui_from_components(): mark_interrupted_schedule_runs()
            before the GUI is built (never in create_tables)
```

- **Opens at the first due delivery,** the only first-dispatch path being
  `_handle_delivery` (`relay_worker.py:1759`): a run stopped before
  anything was due leaves the previous record. A failed write prints a
  Terminal line, and the deliveries go on. `run_plan` = `{animal_id:
  {relay_unit_id, requested_ml, planned_ml, q_ml, complete_ml}}` covers
  every instant delivery, past ones included, or each staggered animal
  with a target above 0 (`relay_worker.py:590-599`).
- **Closes once per worker** (`run_end_recorded`). An operator Stop is
  recorded by `stop_program` with its StopResult, since the queued
  `finished` can run inside Stop's event pump (`main.py:536`).
  Reconciliation stays out of `create_tables`, which `--selftest`
  (`main.py:139`) and `tools/set_valve_topology.py` run while RRR may be up.
- **Hot-path cost:** one attribute check per delivery, and one INSERT
  transaction at a run's first dispatch on the worker thread, as the ledger
  writes are [SD-card cost NEEDS CONFIRMATION]. Stop adds one UPDATE and
  one `logs` INSERT after the relays are off, Run one indexed read (§9).
  The pulse loop gains only S6's two cancel checks; `log_delivery` is
  unchanged.

**The outcome rule** (D2), per animal; `complete_ml` is fixed at the first
dispatch. An animal below its threshold is `stopped` (operator Stop) or
`incomplete`.

| Run | `completed` iff delivered ≥ | Basis |
|---|---|---|
| Staggered, any mode | scheduled − `_completion_tolerance_ml`: max(0.01, q/2) under nearest, 1e-6 under round-up, 0.01 without a quantum | the worker's own completion test (`relay_worker.py:_completion_tolerance_ml:1115-1161`, used at `:1358`) |
| Instant, pulse mode | min(planned − q/2, scheduled − tol), tol as for staggered with a quantum | D2, or the worker's tolerance of the ask: a retry re-plans the ask minus what was dispensed (`relay_worker.py:_quantize_to_pulses:873-880`) |
| Instant, pump or continuous | planned − 0.01 (planned = scheduled) | D2's non-pulse case |

- The comparison has a 1e-9 slack. `end_reason` is `completed`, `stopped`
  or `ended_short`; only reconciliation sets `interrupted`.
- **One pulse short is red,** except where RRR's own completion test counts
  the animal done, under nearest: at an exact half-pulse tie (PR 6 rounds
  the plan up, so one pulse less is scheduled − q/2), or below 0.02 mL per
  pulse (the 0.01 mL floor exceeds half a pulse). The production 0.034164
  mL per pulse meets neither. Off-grid credits the worker accepts (late
  close, sensor blend) are never red: none in 1092 + 1040 probe deliveries.

**Audit row.** One `logs` row per operator Stop, through
`log_action(trainer_id or 0, 'schedule_stopped', details)`
(`database_handler.py:1015`); none for a Stop during "Starting…":

```
AM water (schedule 12, run 41) stopped by alice: animal 3 0.410 of 0.410 mL planned; animal 5 0.410 of 0.991 mL planned. Relays confirmed off: yes; worker exited: yes
```

---

## 6. Stop (PR 2)

Stop becomes the only way to end a run, so it takes over CLOSE ALL
RELAYS' safety duties.

| | Change | Fixes |
|---|---|---|
| S1 | Cancel the worker right after the first all-off, before the dialog pumps events | a pulse starting after the all-off |
| S2 | All relays off again after the teardown (when a worker or thread existed); that last command decides "confirmed off" | `cleanup()` switches the relays off again later, but its result is only printed (`main.py:462`) |
| S3 | The latch: when `not result.safe`, SCHEDULE passes to EMERGENCY in one step (`OperationLock.hold_until_safe`), before `reset_ui` and any dialog. Run, Change Relay Hats, priming, calibration and topology changes stay refused until a confirmed CLOSE ALL RELAYS or a restart | `reset_ui` releasing the lock regardless |
| S4 | One dialog: **Relays Not Confirmed Off** or **Delivery Worker Did Not Stop** | two dialogs, or none |
| S5 | Run refuses beside a live worker thread, keeps its reference and latches (**Delivery Worker Did Not Stop**); another failed start says **Schedule not started**; `main.cleanup` keeps a running thread | dropping a running QThread |
| S6 | A cancel check before the manifold prime and before the master hold | a Stop reopening the master (`solenoid_flow_strategy.py:1125, :1208-1210`) |
| S8 | A Stop during "Starting…" cancels the queued start (a run token) | a start that launches after the Stop, which nothing could end once CLOSE ALL no longer stops schedules |

- `execute_stop_sequence(handler, worker_obj, thread_obj, signals,
  dialog_factory=None)` returns `StopResult(relays_confirmed_off,
  worker_exited)` with `.safe`; `on_unsafe` goes. `main.run_program`
  returns whether the thread started; `main.stop_program` never raises. A
  Stop that fails before the sequence runs leaves the job and Stop live.
- S7 of the approved plan (Stop without a login) is dropped for D3. No
  valve stays open after Stop returns, but one may still open briefly (the
  hold, or one pulse of at most 30 ms) before the worker's next check
  [NEEDS CONFIRMATION on a rig].

---

## 7. Who can end a run (PRs 3, 4)

CLOSE ALL RELAYS, Close Selected and Log Out are unavailable exactly while
a schedule job is in progress: from the Run click ("Starting…"), through a
staggered run waiting for its window, to the end of the run or of Stop.

| State | `job_in_progress` | Lock | CLOSE ALL RELAYS / Close Selected | Log Out |
|---|---|---|---|---|
| Idle | False | none | enabled | enabled |
| Priming | False | PRIMING | enabled | enabled |
| Calibration | False | CALIBRATION | behind the modal wizard (as today) | as today |
| Run click → end of the run or of Stop | True | SCHEDULE | **greyed + refused** | **greyed + refused** |
| After an unsafe Stop | False | EMERGENCY | enabled: a fresh handler; clears the latch only when every relay is confirmed off | enabled |
| Stale SCHEDULE hold | False | SCHEDULE | enabled (force-release failsafe) | enabled |

- **Two layers** (`operation_lock.py:19-23`): greyed with the tooltip "A
  schedule is running: press Stop to end it" (Log Out's adds ", then log
  out"), and refused first thing in each handler (**Schedule running**).
  The predicate, `RunStopSection.job_in_progress`, replaces
  `PrimingControlWidget`'s `stop_schedule` (as `schedule_running`) and
  reaches `UserTab` (`gui.py:182`); PR 3 sets it **before**
  `try_acquire(SCHEDULE)`. Stop needs a login (`run_stop_section.py:233`),
  hence D3.
- **CLOSE ALL RELAYS no longer stops a schedule;** its all-off, fresh
  handler, latch and failsafe stay, and Close Master is unchanged. The
  `[VALVE CRITICAL]` alarms end "Check the rig; the Stop button switches
  every relay off and stops the schedule." A cage change keeps Close
  Selected greyed; `QPushButton[variant="danger"]:disabled` keeps a greyed
  CLOSE ALL RELAYS from painting red.

---

## 8. Animals tab and export (PRs 8, 9)

The last column, **Last schedule delivered amount**, shows `last_run`
(D4), volumes to three decimals:

| Outcome | Cell | Red |
|---|---|---|
| none | `—` | no |
| running | `Running · {planned} mL planned` | no |
| completed | `{delivered} mL` | no |
| stopped | `Stopped · {delivered} / {planned} mL` | yes |
| incomplete | `Incomplete · {delivered} / {planned} mL` | yes |
| interrupted | `Interrupted · ? / {planned} mL` | yes |
| a newer release's value, after a revert | `{Outcome} · {delivered} / {planned} mL` | yes |

- **Tooltip:** the schedule, when the run ended ("2 hours ago (YYYY-MM-DD
  HH:MM)"; an interrupted run by its start), and `Scheduled:`, `Planned:`,
  `Delivered:` lines. A red staggered cell gives the remainder (scheduled −
  delivered) for a new schedule; a red instant cell points to the delivery
  log first (§14, item 8). An unknown amount shows "?" and the command to
  type on the Pi (D10): `cd ~/rrr/current/Project &&
  ~/rrr/shared/venv/bin/python3 tools/gravimetric_check.py daily --since
  <YYYY-MM-DD> --cage <n>`.
- **Drawing (D9).** A `QStyledItemDelegate` fills the cell with `alertFill`
  and draws `alertText`, `pyqtProperty(QColor)` values from the QSS
  (`QWidget#AnimalsTab { qproperty-alertFill: #DC2626; qproperty-alertText:
  #FFFFFF; }`, both themes; 4.83:1, WCAG AA). A status word, never colour
  alone; the text stays in the item for the filter and selection.
- **Layout and refresh.** `len(COLUMN_WIDTHS)` replaces the 7s, and the
  columns 5–6 widening goes. The tab reloads after a run and when
  selected, keeping filter and selection. The words live in the Qt-free
  `utils/last_run_text.py`, shared with the export and D5.
- **Export Animals to CSV** gains `Last Schedule`, `Last Schedule Result`,
  `Last Schedule Scheduled (mL)`, `Last Schedule Planned (mL)`,
  `Last Schedule Delivered (mL)`, `Last Schedule Started` and
  `Last Schedule Ended`. Delivered is empty when unknown (never 0), and
  Ended is empty for an interrupted run.

---

## 9. Run warnings (PRs 10, 11)

Run asks at most one question, after the **Expired Schedule** refusal: the
window note and a last-run paragraph go inside it, never into a second
dialog. Each question is plain text with Cancel as the default and Esc
button; every Cancel goes through `_reset_run_button`. The words live in
Qt-free `utils/run_warnings.py`.

| Mode | Times passed? | Last run of this schedule | Question |
|---|---|---|---|
| Staggered | start passed | none, or no water went out | **Schedule Start Time Passed** (unchanged) |
| Staggered | either | ended early (any animal) | **Last Run Ended Early**, with the window note when the start has passed |
| Staggered | either | completed (no animal ended early) | the completed-run question (PR 11 words it), with the window note when the start has passed |
| Instant | some passed | any | **Some Deliveries Passed**, with a last-run paragraph when the last run ended early or completed |
| Instant | none passed | ended early or completed | **Last Run Ended Early**, or the completed-run question |

Any other case asks nothing. An instant schedule whose last run completed
has all its delivery times behind it, so **Expired Schedule** refuses it
first (`run_stop_section.py:492-500`). Only an edit that moves its times
brings it to the instant rows: the edited schedule keeps its `schedule_id`,
and so its run history (`schedules_hub.py:288, :298`).

**Some Deliveries Passed** (D6; **Start Run** / Cancel) replaces today's
Yes/No question (`run_stop_section.py:502-516`). RRR creates one delivery
per animal (`schedule_wizard.py:336-341`; the editor refuses more,
`schedules_hub.py:136-145`):

```
2 of 4 deliveries of "PM water" have already passed. This run skips them:
• M-011, cage 3: 08:00 passed, nothing from this run (0.250 mL scheduled)
• M-012, cage 4: 11:00 passed, nothing from this run (0.300 mL scheduled)

This run delivers 0.600 of the 1.150 mL scheduled. For the animals above, the Animals tab will show this run in red as incomplete.

Start the 2 deliveries still ahead?
```

**Last Run Ended Early** (D5; **Start Over** / Cancel) appears when an
animal's latest run **of this schedule** is `stopped`, `incomplete`,
`interrupted` or a leftover `running`, and some water went out (delivered
above 0, or unknown). It lists every animal that got water, completed ones
too, since Start Over doses them again ("M-011, cage 3: 0.410 of the
planned 0.991 mL, stopped at 10:32; remaining 0.590 of the 1.000 mL
scheduled"), and says to create a new schedule for the remaining amount.

- **Instant schedules:** re-running skips the passed times
  (`relay_worker.py:496-527`), so their lines carry no remainder and add
  "Passed deliveries are skipped, never repeated."
- **A completed last run** gets the completed-run question (the owner's
  choice on refinement 7; PR 11 words it), placed as the table shows: Run
  would otherwise give every animal its full amount again unasked.
- **One indexed read** (`get_latest_runs_of_schedule`) per Run; if it
  fails, a Terminal line is printed and the question skipped.

---

## 10. Edge cases

| Case | Behaviour |
|---|---|
| Stop pressed repeatedly | `stop_program` returns without a job; `RelayWorker.stop` is idempotent; one record close per worker |
| Stop before the first delivery | No record; one "before its first delivery" audit row |
| Crash or power loss | `running` until the next start marks it `interrupted`; that start's HAT set-up switches every relay off (`gpio_handler.py:_initialize_hats:162, :181`) [whether a HAT holds its outputs through a power loss NEEDS CONFIRMATION] |
| Relays not confirmed off | Outcome from the credited volume; `relays_confirmed_off` = 0; Stop latches. A valve stuck open cannot be measured |
| An abandoned worker holds the DB lock | The finish returns False after about 5 s; the tab shows **Running** until the next start marks the run `interrupted` (errs red) |
| Schedule edited or deleted | The run keeps its copied name and figures |
| Instant animal whose only delivery had passed (Q5 × Q7) | In the run with delivered 0, `incomplete`, red, even if an earlier run watered it; **Some Deliveries Passed** says so first |
| Revert to 1.21.x | Tables ignored; CLOSE ALL RELAYS as in 1.21.x; runs there are not recorded |
| Two RRR versions at once | The other would mark a live run `interrupted`; the single-instance guard is per version (`main.py:791`), and updates are refused during a run |

---

## 11. Limitations

- **Delivered is credited, not weighed;** nothing reads a relay back. A
  pulse cut by Stop is credited whole (at most one pulse over) [NEEDS
  CONFIRMATION physically]; a terminated worker never credits its attempt
  in flight, so delivered is then a lower bound.
- **Continuous and pump modes** cannot be cancelled mid-delivery; every
  start resets to solenoid pulse mode, so they stay documented, not fixed.
- **The Execution Monitor is unchanged:** "Incomplete" below 95 %
  (`ScheduleProgressTracker.py:464`), and an instant animal's target is the
  all-animal total (`run_stop_section.py:784`).

---

## 12. Delivery plan

**Version: 2.0.0 (MAJOR),** by
[MAINTENANCE.md §2](MAINTENANCE.md#2-picking-the-version-number--semver-for-rrr) (D11):

- **Data: MINOR** (two auto-created tables that older releases ignore;
  MAINTENANCE.md:83, :101). **Behaviour: MAJOR.** Operators **must** end a
  run with Stop, though 1.21.0's notes and alarms say CLOSE ALL RELAYS does
  (CHANGELOG.md:83-88), and **must** stop or wait before logging out: two
  "Operators must…" lines (MAINTENANCE.md:118-121, :127). The set-up-step
  exception (:128-132) does not apply; ties go higher (:133-135).
- **Stop and ask (MAINTENANCE.md:105-108):** it cannot be designed
  backwards-compatible. The owner's request (CLOSE ALL RELAYS and Close
  Selected unavailable during a run) and Q4 (logout blocked) *are* the
  incompatible changes; the data side is revert-safe (§4).
- **No cost, no `-beta`:** the updater compares integer tuples
  (`updater.py:31-49`); `/releases/latest` excludes pre-releases
  (`updater.py:27`), and TOPOLOGY_VALIDATION.md:12 forbids `-beta` on rigs.

**The train,** in merge order; release-bound subjects end "(v2.0.0)":

| Order | PR | Branch | Version |
|---|---|---|---|
| any, best before 2 | 0 Installer re-exec after the pull | `fix/installer-reexec-after-pull` | none; untagged |
| 1 | 1 This record; the MAINTENANCE §3a one-bump sentence | `docs/stop-partial-delivery-design` | none (§3c) |
| 2 | 2 Stop hardening, S1–S6 + S8 (§6) | `fix/stop-takes-over-close-all` | **sets 2.0.0**, opens `## 2.0.0` |
| 3 | 3 CLOSE ALL RELAYS / Close Selected unavailable mid-run (§7) | `feat/close-all-priming-only` | adds lines |
| 4 | 4 Log Out blocked mid-run (§7) | `feat/block-logout-during-run` | adds lines |
| 5 | 5 Run-history tables, facade, `Animal.last_run` (§4) | `feat/schedule-run-history` | adds lines |
| 6 | 6 One whole-pulse rounding (D1) | `fix/round-half-pulse-ties` | adds lines |
| 7 | 7 Record each run, reconciliation, audit row (§5) | `feat/record-schedule-runs` | adds lines |
| 8 | 8 Animals-tab column, red cell, Help (§8) | `feat/animals-last-schedule-column` | adds lines |
| 9 | 9 CSV export columns (§8) | `feat/export-last-schedule` | adds lines |
| 10 | 10 Some Deliveries Passed (§9) | `feat/warn-instant-passed-deliveries` | adds lines |
| 11 | 11 Last Run Ended Early and the completed-run question (§9) | `feat/run-warns-stopped-schedule` | adds lines |
| 12 | 12 Headless integration test | `chore/stop-partial-delivery-integration-test` | none (test-only) |
| 13 | 13 Operator docs, smoke test, release notes | `docs/v2-0-0-operator-docs` | finalises the entry |
| T | Tag `v2.0.0` on the validated SHA, at the owner's go | — | — |
| later | Palette B | its own series | **2.1.0**, merged after the tag |

- **PR 3 never merges before PR 2** (the latch and the second all-off),
  and is never tagged without it. The train is tagged whole; if it must be
  cut short, the smallest safe release is PRs 1–4 plus their notes (still
  2.0.0, MAJOR), and PRs 5–11 then follow as 2.1.0, palette B as 2.2.0.
- **One bump per release:** only PR 2 edits `version.py`; the other PRs add
  their lines under `## 2.0.0`, as v1.21.0's train did. PR 1 writes this
  into MAINTENANCE §3a. A code fix found while validating the merged
  candidate follows §3b (2.0.1, folding 2.0.0 into its entry, tag
  `v2.0.1`); doc-only and test-only fixes do not bump.
- **No v1.21.1 tag:** PR 0 is tooling-only (CONTRIBUTING.md:106-107):
  `install.sh` and `bootstrap.sh` are not shipped (:111-113), and the
  in-app update never runs the bundle's `scripts/install`. It ships
  untagged, with a line in the 2.0.0 entry.
- **Palette B is v2.1.0,** merged after the 2.0.0 tag (from PR 2 on, `main`
  says 2.0.0), carrying the QSS rules of §7 and §8.
- **Before the tag,** on the final SHA with CI green (`ubuntu-24.04`,
  #190): MAINTENANCE §5 on the home Pi as PR 13 extends it; a wet check
  weighing a stopped staggered run against the cell and
  `gravimetric_check.py daily` (§14, item 17); every rig that ran the
  candidate goes back to v1.21.0 before the tag and updates in-app after.
- **Rollback:** **Revert to previous version** keeps the database and is
  refused during a run (`updater.py:revert:393-414`); the launcher reverts
  after two failed starts. Older releases ignore the tables; back on 2.0.x
  an open run becomes `interrupted`. A bad published release gets the next
  PATCH (MAINTENANCE §6.3).

---

## 13. Out of scope

Item (d) (a full dose logged `partial`); the Execution Monitor's targets
and 95 % rule; the continuous and pump Stop gaps; a stalled staggered run;
the dead `update_schedule_status` / `get_schedule_progress`; a real resume
(Q6). Backlog: the `.xlsx` export's openpyxl dependency; MAINTENANCE §2's
beta-channel wording; `gui.closeEvent` after an abandoned worker; a click
guard for Change Relay Hats; two simultaneous "Stopping" dialogs; a
session-scoped `qapp` fixture; D5/D6 counts one short when a delivery
comes due during a question; the Run questions after the refusals; the
I²C coordinator's sleep under its lock; a sensor-mode cancel check after
the sensor restart; a note in Emergency Controls during a run; Help's
stale "Access and Modes" guest sentence; editable Animals cells; the dark
zebra rows (palette B).

---

## 14. Refinements acknowledged

Where the design departs from a literal answer or the approved plan. The
owner acknowledged every item on 2026-10-09; the choices made are shown.

| # | Refinement | Reason |
|---|---|---|
| 1 | The outcome rule is per mode (§5), not planned − q/2 alone | Credits land off the pulse grid (a late close: 14.30 of 15 pulses, which the worker calls done). The literal rule made 30 of 390 sensor-blended windows and 91 (nearest) / 84 (round-up) of 462 retried instant deliveries red. The one-pulse exception is Q2's "worker's whole-pulse tolerance" |
| 2 | PR 6 changes dosing at exact half-pulse ties: one pulse more, at most q | 74 of 6000 surveyed windows change, only at few-digit calibrations; production meets none. Older ledger rows at ties re-grade as `mismatch`. **Accepted** |
| 3 | A delegate, not the approved plan's QLabel cell widget | A cell widget paints a band inside the padding and `setForeground` turns teal when selected; a delegate fills the cell and follows the theme |
| 4 | 2.0.0 MAJOR, not "next MINOR" | MAINTENANCE §2 (§12). **Chosen:** 2.0.0, then palette B as 2.1.0 |
| 5 | No v1.21.1 tag | The app would be identical to 1.21.0. **Chosen:** PR 0 ships untagged |
| 6 | D3 trade-off | A staggered run waiting days keeps its user logged in (a second operator works in that session), and CLOSE ALL RELAYS, Close Selected and Log Out grey, until someone presses Stop |
| 7 | D5 extensions: interrupted and leftover `running` runs warn; completed animals are listed | Start Over doses them again. **Chosen:** Run also warns before re-running a schedule whose last run completed (PR 11) |
| 8 | Instant advice differs from D5's "delivers the full amount again" | Re-running skips passed times, so the operator checks the delivery log before a remainder schedule (no double water); the Q5 × Q7 case follows (§10) |
| 9 | The D5 reader is `get_latest_runs_of_schedule`; `get_latest_schedule_runs` is not added | Nothing would call it |
| 10 | S8 uses a run token, not a `job_in_progress` re-check | The queued start ran inside Stop's event pump while the flag was still True |
| 11 | One bump per release; a validation fix follows §3b | 102c136a (#149) set 1.21.0, and the 39 PRs merged after it did not bump. Unlike #187 and #189 (kept at 1.21.0), a validation fix bumps to 2.0.1, so every candidate on a device has its own number |
| 12 | Unknown means unknown | "?" and the log command for any unrecorded amount. An interrupted run's `ended_at` is the restart time, so the tooltip dates it by `started_at` and the export's Ended is empty |
| 13 | No audit row for a Stop during "Starting…" | No worker existed, and nothing ran |
| 14 | CLAUDE.md R2 trigger 1, at its borderline | **Chosen:** the module `models/schedule_runs_repo.py`, minimal, behind the facade (§4). R1 is not paired: `CREATE TABLE IF NOT EXISTS` migrates nothing |
| 15 | Reload on tab change and after a run, no new signal | A tab on screen at the first delivery shows **Running** at the next tab change |
| 16 | The latch keys on `StopResult.worker_exited`, not `updater.is_busy()` | Both read the same QThread and agree in every reachable case |
| 17 | Wet validation | An untagged candidate goes on a rig with an animal, or in TOPOLOGY_VALIDATION, only with the owner's OK. **Chosen:** OK; such rigs return to v1.21.0 before the tag |

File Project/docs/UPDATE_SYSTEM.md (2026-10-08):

# RRR Update System — Design

**Status:** Phase 2 shipped (v1.4.0) — Phase 3 (offline + signing) deferred · **Date:** 2026-05-19 · **Owner:** zepaulojr1

> Line numbers in the code links below are from the 2026-05-19 audit. That
> code has since moved (Phase 2a onwards), so each link opens the current
> file, not the line that was audited.

Design for shipping updates to deployed Rodent Refreshment Regulator (RRR) devices —
automatically, safely, and without requiring operators to touch a terminal.

---

## 1. Goals & Constraints

| Goal | Decision |
|---|---|
| Trigger model | **In-app prompt + explicit approve.** App detects updates, operator clicks to apply. No surprise changes on a device delivering water to live animals. |
| Release source | **Tagged GitHub Releases only.** No shipping `main` HEAD. Every release is QA-gated. |
| Connectivity | **Online and offline both supported.** Same artifact applies either way. |
| Operators | **Non-technical researchers.** Update flow is 100% GUI. No git, no shell. |
| Platform | Raspberry Pi OS Bookworm (64-bit), per `README.md`. |

**Non-goals:** OS/firmware updates, multi-device fleet orchestration (future), delta updates.

---

## 2. Why the current model must change

Updates today run `git pull --ff-only` ([scripts/install/20-repo.sh:34](../../scripts/install/20-repo.sh),
[bootstrap.sh:41](../../bootstrap.sh)). For a non-technical operator on a lab device this fails on
four counts:

1. **Not atomic** — an interrupted pull leaves a half-updated checkout. The device is bricked
   with no clean state to boot from.
2. **No rollback** — a bad release cannot be reverted without a terminal.
3. **No offline path** — `git pull` needs network; air-gapped labs cannot update at all.
4. **Dirty-tree failure** — the SQLite DB and `settings.json` are written *inside the git
   checkout* (see §7). `--ff-only` aborts the moment they diverge, which is immediately.

The fix: stop updating code in place, and stop using git as the delivery mechanism on devices.

---

## 3. Architecture Overview

```
  DEVELOPER                      GITHUB                         DEVICE (Raspberry Pi)
  ─────────                      ──────                         ─────────────────────
  git tag v1.1.0  ──push──▶  Actions: build bundle        ┌──────────────────────────┐
                             ├─ rrr-1.1.0.rrrupdate       │  App (Updates panel)     │
                             ├─ minisign signature        │   ├─ online: latest.json │
                             ├─ SHA256                    │   └─ offline: USB file   │
                             └─ latest.json  ──────────▶  │             │            │
                                  (Release assets)        │             ▼            │
                                                          │     verify → apply       │
                                                          │     engine (§6)          │
                                                          └──────────────────────────┘
```

A release is **one signed bundle file**. Online, the device downloads it. Offline, the operator
copies it from a USB stick. From that point the apply path is identical.

---

## 4. Versioning

Single source of truth — new file `Project/version.py`:

```python
__version__ = "1.0.0"   # SemVer: MAJOR.MINOR.PATCH
```

- The app displays it (About / Updates panel) and uses it for comparison.
- A release is an **annotated git tag** `vX.Y.Z` matching `__version__`.
- CI rejects a tag whose name ≠ `version.py` (prevents drift).
- SemVer rule of thumb for this project: **MAJOR** = breaking DB migration or hardware-protocol
  change, **MINOR** = features, **PATCH** = fixes.

First action: set `1.0.0`, cut tag `v1.0.0` from the current `main`.

### 4.1 Cutting a release — operational runbook

1. **Decide the version** per the SemVer rule above (MAJOR = breaking DB
   migration or hardware-protocol change; MINOR = backward-compatible features;
   PATCH = fixes).
2. **Bump `Project/version.py`.** It is the only place the version lives.
3. **Land it on `main`.** Commit the bump (with release notes) and merge via
   PR. Releases are cut from `main` only — never a feature branch or arbitrary
   commit.
4. **Sanity-check the bundle locally** (recommended):
   `bash scripts/release/build-bundle.sh` → inspect
   `dist/rrr-<version>.rrrupdate`. Confirm it contains no virtualenv, build
   artifacts, or device data.
5. **Pull `main`, then tag and push.** The tag MUST be `v<__version__>`
   exactly; pre-release uses a `-beta` suffix (`v1.2.0-beta`). **Always
   fast-forward `main` first** — otherwise `git tag` silently marks whatever
   stale commit local `main` points at, and CI rejects the mismatch:

   ```sh
   git checkout main
   git pull --ff-only origin main   # the step that bites if skipped
   git tag v1.2.0
   git push origin v1.2.0           # point of no return — publishes the release
   ```

6. **CI does the rest.** `.github/workflows/release.yml` fires on the tag,
   verifies the tag matches `Project/version.py` (fails the build if not),
   takes the Release notes from the version's `CHANGELOG.md` entry (fails
   before publishing if there is none), builds the bundle, and publishes a
   GitHub Release with the `.rrrupdate` bundle, its `.sha256`, and
   `latest.json` attached. The Updates tab shows those notes.

#### Recovery — tagged the wrong commit

```sh
git tag -d v1.2.0
git push origin :refs/tags/v1.2.0
# then pull main and re-tag as above
```

#### Invariants

- The git tag and `Project/version.py` must always agree — CI enforces this.
- Do not hand-edit `dist/` or upload release assets manually; the workflow
  owns them.
- Never ship updates by telling users to `git pull`. Tagged GitHub Releases
  are the only supported channel.

---

## 5. Release artifact & layout

### 5.1 Blue-green release directories

Replace "git clone run in place" with versioned, immutable release directories and an atomic
`current` symlink — the standard appliance-update pattern (RAUC/Mender), simplified:

```
~/rrr/
├── releases/
│   ├── 1.0.0/            ← extracted bundle, treated as read-only
│   └── 1.1.0/
├── current -> releases/1.1.0      ← atomic symlink; apply = swap, rollback = swap back
└── shared/                        ← PERSISTS across every update
    ├── venv/
    ├── rrr_database.db
    ├── settings/settings.json
    └── logs/
```

[scripts/runtime/launch.sh](../../scripts/runtime/launch.sh) changes to follow `~/rrr/current`
instead of `~/rodRefReg`. The git clone remains, but **only as a developer workflow** — devices
no longer run from it.

### 5.2 The bundle — `rrr-X.Y.Z.rrrupdate`

A `tar.gz` containing:

- `Project/` and `scripts/` (application code for this version)
- `requirements.txt`
- `wheels/` — pip wheels vendored for offline install. Small: PyQt5/pandas/numpy come from
  apt `--system-site-packages`, so only `requests`, `slack_sdk`, `smbus2`, `pyserial` ship here.
- `migrations/` — forward-only DB migration scripts (see §7).
- `manifest.json` — `version`, `min_upgradable_from`, `changelog`, `requirements_hash`.

### 5.3 Release manifest — `latest.json` (separate Release asset)

```json
{
  "version": "1.1.0",
  "url": "https://github.com/Corticomics/rodRefReg/releases/download/v1.1.0/rrr-1.1.0.rrrupdate",
  "sha256": "…",
  "signature": "…",            // minisign detached sig
  "min_upgradable_from": "1.0.0",
  "channel": "stable",
  "changelog": "…"
}
```

The app fetches this one small file to decide whether an update exists.

### 5.4 Channels

`stable` (default) and `beta` (GitHub *pre-releases*). Operators stay on `stable`; a developer
can opt a test device into `beta`. One field in `settings.json`.

---

## 6. The apply engine — `Project/utils/updater.py`

Online and offline both converge here. Steps, in order, **fail-safe** (any failure before
step 7 aborts with the old version fully intact):

1. **Safety gate.** Refuse to apply if a delivery schedule is actively running. Live animals
   depend on the running process — this is a hard block, not a dismissible prompt.
2. **Verify integrity.** Check SHA256 **and** the minisign signature against the public key
   committed in the repo. Critical for the offline path — a USB stick is the realistic tamper
   and corruption vector. Reject on mismatch.
3. **Check compatibility.** Refuse if `current version < manifest.min_upgradable_from`
   (forces stepwise upgrades when a migration chain requires it).
4. **Extract** to `releases/<new>/`.
5. **Provision venv.** If `requirements_hash` differs from the installed one, `pip install`
   from `wheels/` (offline-capable). Otherwise reuse `shared/venv` untouched.
6. **Migrate data** — run pending forward-only migrations against `shared/rrr_database.db`
   inside a transaction; **back up the DB first** to `shared/backups/`.
7. **Health check.** Launch the new release in a subprocess with a `--selftest` flag: import
   the core modules and open the DB (it does not touch the relay HATs). Must exit 0 within a
   timeout.
8. **Commit.** Atomically swap the `current` symlink → `restart` the systemd user service
   (`systemctl --user restart rrr`). If the app was launched manually, prompt the operator to
   restart instead.

### Rollback

- Keep the last **3** releases on disk; prune older.
- **Manual:** an Updates-panel button — "Revert to previous version" — swaps the symlink back.
- **Automatic:** a boot sentinel. The launcher writes a "boot attempt" marker; the app clears
  it once it reaches a healthy idle state. If the marker shows **2 consecutive failed boots**,
  the launcher reverts `current` to the prior release and restarts. A bad release can never
  permanently brick a device.

---

## 7. Data migration (audit findings)

The blue-green model only works if persistent data lives **outside** the release directory.
Today it does not. Audit of the current code:

| Data | Today | Code | Move to |
|---|---|---|---|
| SQLite DB `rrr_database.db` | **Inside repo** (`Project/`, CWD-relative) | [models/database_handler.py:12](../../Project/models/database_handler.py) | `~/rrr/shared/rrr_database.db` |
| `settings.json` | **Inside repo** (`Project/settings/`) | `settings/config.py:5` (file removed in v1.5.0, when settings moved to SQLite) | `~/rrr/shared/settings/settings.json` |
| Slack credentials | **Inside repo**, CWD-relative `settings.json` — buggy | [ui/SlackCredentialsTab.py:41](../../Project/ui/SlackCredentialsTab.py) | same as above; **fix the CWD-relative path** |
| Runtime log `~/rrr_app_debug.log` | Outside repo (`$HOME`) | [main.py:28](../../Project/main.py) | `~/rrr/shared/logs/` |
| User exports / backups | Outside (operator-chosen) | [ui/SettingsTab.py:1425](../../Project/ui/SettingsTab.py) | no change |

**Required work:**

1. Introduce a `paths` module — a single function resolving the data root
   (`$RRR_DATA` → `~/rrr/shared` → legacy in-repo fallback). All of the call sites above route
   through it. This kills the CWD-relative bugs.
2. **One-time install migration:** on first run under the new layout, if `shared/` is empty but
   a legacy in-repo DB/settings exist, copy them into `shared/`.
3. Forward-only DB migrations: a `schema_version` table + ordered scripts in the bundle's
   `migrations/`. Never auto-downgrade — that is what rollback's DB backup (step 6) covers.

This is the largest piece of work and the main risk in the plan. It is contained entirely in
Phase 2.

---

## 8. User experience

For non-technical researchers, the entire flow is two screens:

- **Banner** — when an update is found, a non-modal bar appears in the main window
  ([ui/gui.py:161](../../Project/ui/gui.py) area): *"RRR 1.1.0 is available."* → `[View]`.
- **Updates panel** — a new sub-tab in Settings (alongside Delivery/Calibration/Priming/General,
  [ui/SettingsTab.py:63](../../Project/ui/SettingsTab.py)). Shows current version, available
  version, changelog, and one primary button **[Update Now]** plus **[Later]**. Also hosts
  **[Check for updates]**, **[Install from file…]** (offline/USB), and **[Revert to previous
  version]**.
- During apply: a progress dialog with the §6 steps. On failure: a plain-language message
  ("Update could not be installed. Your system is unchanged.") and a log path for support.

The update check runs in a background `QThread` on launch — if there is no network it is a
silent no-op, never a blocking error.

---

## 9. Security

- **Signing:** every bundle is signed with **minisign** (small, single-binary, no GPG keyring
  pain). The public key is committed to the repo; the private key lives only in GitHub Actions
  secrets. The device verifies the signature before extracting (§6 step 2).
- **Transport:** downloads over HTTPS from `github.com` only.
- **Offline trust:** the signature — not TLS — is what protects the USB path. A bundle from an
  untrusted stick is rejected exactly like a tampered download.
- **No elevation:** updates apply entirely within the user's `~/rrr` and the user systemd
  service. No `sudo`, no system-wide writes.

---

## 10. CI/CD — release pipeline

GitHub Actions workflow, triggered on `push` of a tag matching `v*`:

1. Assert tag name == `Project/version.py`.
2. Build `rrr-X.Y.Z.rrrupdate` (code + vendored wheels + migrations + `manifest.json`).
3. Compute SHA256; sign with minisign.
4. Generate `latest.json`.
5. Create the GitHub Release (pre-release if the tag is `-beta`), attach all assets.

Result: cutting a release is `git tag v1.1.0 && git push --tags`. Nothing manual.

---

## 11. Rollout plan — phased, each phase independently shippable

| Phase | Scope | Outcome | Risk |
|---|---|---|---|
| **0 — Versioning** | `version.py`; tag `v1.0.0`; GitHub Actions release workflow producing a bundle + SHA256 | Releases exist and are reproducible | None |
| **1 — Notify** | In-app update check + banner + Updates panel (read-only — tells the operator a version is available) | Operators *know* when they are out of date | Low — no apply logic yet |
| **2 — Apply** | Blue-green layout, `paths` module + data migration (§7), apply engine, rollback | One-click updates with rollback | **Medium** — the data migration |
| **3 — Harden** | Offline USB import, minisign signing/verification, `beta` channel, auto-rollback boot sentinel | Offline support + supply-chain integrity | Low |

Phases 0–1 ship value with near-zero risk and can go out immediately. Phase 2 is the real
engineering effort and should be tested on a non-production Pi before fleet rollout.

---

## 12. Resolved decisions (evidence-backed)

The three pre-Phase-2 questions, resolved against the actual codebase rather than assumption.

### 12.1 Migration timing → **installer-run**

Relocate data in the installer, not at app launch.

- The DB is created safely on demand — `create_tables()` runs in `__init__` with
  `CREATE TABLE IF NOT EXISTS` for every table
  ([database_handler.py:57-247](../../Project/models/database_handler.py)); a missing DB never
  crashes the app.
- **But `DatabaseHandler()` is instantiated in three uncoordinated places** —
  [main.py:115](../../Project/main.py), [splash_screen.py:53](../../Project/ui/splash_screen.py),
  [schedule_drop_area.py:22](../../Project/ui/schedule_drop_area.py) — each with the default
  CWD-relative `rrr_database.db`. An in-app migration would race: whichever site runs first
  creates a fresh empty DB in the wrong location.
- The installer is the opposite — one serialized step that already runs Python
  ([30-python.sh:11](../../scripts/install/30-python.sh)) and already does protected file copies
  ([40-hardware.sh:91](../../scripts/install/40-hardware.sh), `cp -n`).

→ Add a relocation step to the installer. The in-app `paths` module (§7) still ships, but only
to *read* the relocated locations, never to perform the move.

### 12.2 Signing key custody → **single maintainer**

- `git shortlog -sn`: `zepaulojr1` = 1273 commits; next contributor = 104. All recent commits
  are `zepaulojr1`.
- No `.github/` existed before this work — no prior CI, no CODEOWNERS.
- README's only contact is `zepaulojr2@gmail.com` ([README.md:246](../../README.md)); no lab
  or institution named.

→ No key-custody policy required. The minisign private key is held by the sole maintainer as a
single GitHub Actions secret. Releases are manual tag pushes at the maintainer's cadence.

### 12.3 Fleet visibility → **deferred; cheap interim win**

- The Slack integration sends only free-text relay/error strings
  ([notifications.py:17-22](../../Project/notifications/notifications.py),
  [main.py:367](../../Project/main.py)) — no device ID, no version.
- No telemetry, analytics, `device_id`, or `machine-id` code exists anywhere in the app.
- No version string is shown in the UI — the window title is the plain
  `"Rodent Refreshment Regulator"` ([gui.py:58](../../Project/ui/gui.py)).

→ A real check-in service is out of scope. Interim win once `version.py` ships: append
`__version__` to the existing Slack startup/error message — basic "which version is this
device on" with zero new infrastructure.

---

## 13. Phase 2 — detailed implementation plan

Phases 0 and 1 only *added* files. Phase 2 changes **where the app runs from** and **where
its data lives** — so it is split into three independently shippable sub-phases, each its own
PR and release.

Phase 2 status of the prerequisites: Phase 0 (versioning + release pipeline) and Phase 1
(in-app update check, shipped as v1.1.0) are done and validated on a Raspberry Pi 5.

### 13.0 Target on-device layout

Guiding principle: **code is disposable and versioned; data is sacred and shared.**

```
~/rrr/                         RRR_HOME
├── releases/
│   └── 1.3.0/                 one extracted release bundle (Project/, scripts/,
│                              requirements.txt, manifest.json, migrations/)
├── current -> releases/1.3.0  atomic symlink — the running version
├── shared/                    survives every update
│   ├── venv/                  the virtualenv
│   ├── data/                  rrr_database.db, settings.json   (RRR_DATA)
│   ├── logs/
│   └── backups/               timestamped DB snapshots taken before each migration
└── state/
    └── boot.json              boot sentinel for auto-rollback
```

The git clone at `~/rodRefReg` **stays**, but only as the installer / build workspace — it is
no longer what the device runs. The runtime is `~/rrr/current`.

### 13.1 Sub-phase 2a — `paths` module  (no behaviour change)  → v1.2.0

The foundation. Centralises every data-file location behind one resolver, with a fallback
that reproduces today's exact paths — so until 2b sets the env var, behaviour is *identical*.

**New file `Project/utils/paths.py`** — resolves locations from the `RRR_DATA` environment
variable, set by the launcher in 2b:

| function | with `RRR_DATA` set | fallback (unset — dev clone / pre-migration) |
|---|---|---|
| `data_dir()` | `$RRR_DATA` | `Project/` (the code dir) |
| `database_path()` | `$RRR_DATA/rrr_database.db` | `Project/rrr_database.db` |
| `settings_path()` | `$RRR_DATA/settings.json` | `Project/settings/settings.json` |
| `debug_log_path()` | `$RRR_DATA/../logs/rrr_app_debug.log` | `~/rrr_app_debug.log` |
| `backups_dir()` | `$RRR_DATA/../backups` | `Project/` |

**Reroute these call sites through `paths`:**

- [models/database_handler.py](../../Project/models/database_handler.py) — default `db_path`
  argument → `paths.database_path()`. The three instantiation sites
  ([main.py:115](../../Project/main.py), [splash_screen.py:53](../../Project/ui/splash_screen.py),
  [schedule_drop_area.py:22](../../Project/ui/schedule_drop_area.py)) pass no path, so they
  all inherit the new default — this is what kills the 3-site race from §12.1.
- `settings/config.py` (removed in v1.5.0, when settings moved to SQLite) — `settings.json` path → `paths.settings_path()`.
- [ui/SlackCredentialsTab.py](../../Project/ui/SlackCredentialsTab.py) — fix the CWD-relative
  `settings.json` write → `paths.settings_path()`.
- [main.py](../../Project/main.py) — `_DEBUG_LOG_PATH` → `paths.debug_log_path()`.

**Risk:** none — with `RRR_DATA` unset every path equals today's. **Test:** the offscreen
`main.setup()` harness already used in Phase 1 validation, plus a unit assertion that the
resolved paths match the legacy paths when the env var is absent.

### 13.2 Sub-phase 2b — blue-green layout + data migration  → v1.3.0

1. **Thin launcher shim.** `~/.local/bin/rrr` becomes a 3-line *stable* shim:
   `exec ~/rrr/current/scripts/runtime/launch.sh "$@"`. It never changes again — so the
   real launch logic, living inside the release, is itself updatable.
2. **New `scripts/runtime/launch.sh`.** Resolves `~/rrr/current`; exports
   `RRR_HOME=~/rrr` and `RRR_DATA=~/rrr/shared/data`; runs `current/Project/main.py` with
   `~/rrr/shared/venv`.
3. **New installer module `scripts/install/55-layout.sh`** — idempotent:
   - create `~/rrr/{releases,shared/{data,logs,backups},state}`;
   - run `build-bundle.sh`, extract the bundle into `releases/<version>/`;
   - create `shared/venv` fresh (`python -m venv --system-site-packages` + pip install) —
     **venvs are not relocatable**, so it is recreated, never moved;
   - run the data migration (§13.4);
   - point `current` → `releases/<version>`; install the thin shim.
4. **systemd unit** `rrr.service` — `ExecStart` already targets `~/.local/bin/rrr` (the
   shim), so no unit change is needed.

Shipping an installer change means each device re-runs the installer once; that single
re-run performs the migration. Existing `~/rodRefReg` installs are detected and migrated.

### 13.3 Sub-phase 2c — apply engine + rollback + UI  → v1.4.0

**`updater.py` additions:**
- `apply_bundle(path)` — gate (refuse if a delivery schedule is running) → verify SHA256 →
  extract to `releases/<new>/` → provision venv only if `requirements_hash` changed → run DB
  migrations (back up first) → health-check → swap `current` → restart.
- `revert()` — swap `current` to the previous release.
- prune — keep the newest 3 under `releases/`.

**`main.py`** — a `--selftest` flag: import core modules, open the DB, exit 0/1. Used as the
health-check before the symlink swap.

**Auto-rollback.** The launcher increments a counter in `state/boot.json`; the app clears it
on reaching a healthy idle state; the launcher reverts `current` after 2 consecutive failed
boots.

**Restart.** If `rrr.service` is active → `systemctl --user restart rrr`; otherwise prompt the
operator to relaunch.

**UI** ([UpdatesTab.py](../../Project/ui/UpdatesTab.py)) — an "Update Now" button driving
`apply_bundle` with a progress dialog, and a "Revert to previous version" button.

Online download only. Offline USB import and minisign signing/verification remain **Phase 3**.

### 13.4 The data migration (the critical step)

Run by `55-layout.sh`, idempotent, **copy-not-move**:

```
if ~/rrr/shared/data/rrr_database.db exists:        skip — already migrated
else:
    locate the legacy DB: ~/rodRefReg/Project/rrr_database.db
    if found:  copy -> shared/data/rrr_database.db
               copy -> shared/backups/<timestamp>/rrr_database.db
    repeat for settings.json (Project/settings/settings.json)
    the legacy copies are LEFT IN PLACE as a fallback — never deleted
```

Forward-only schema migrations: a `schema_version` table plus ordered scripts under
`releases/<v>/migrations/`; the app applies pending ones at startup after backing up the DB.
Downgrades are never automatic — rollback relies on the pre-migration backup.

### 13.5 Validating 2b on the test Pi

The Pi 5 already carries an old-style `~/rodRefReg` install. Validating 2b = re-running the
installer on it and confirming: data lands in `~/rrr/shared/data`, the app runs from
`~/rrr/current`, the legacy DB is preserved, and a second installer run changes nothing
(idempotency).

### 13.6 Decisions already made (flag on review if you disagree)

- Virtualenv is **recreated** in `shared/venv`, not moved (venvs hard-code absolute paths).
- `~/.local/bin/rrr` is a **thin immutable shim**; the real launch logic ships in the release.
- The git clone **stays** as the installer/build workspace; it is not the runtime.
- The installer migration step is **copy-not-move with timestamped backups** — the biggest
  risk in Phase 2 is data loss, and this makes the migration non-destructive and reversible.

### 13.7 Rollout

| Sub-phase | Release | Risk | How users get it |
|---|---|---|---|
| 2a — `paths` module | v1.2.0 | none | normal release |
| 2b — blue-green + migration | v1.3.0 | medium | one installer re-run per device |
| 2c — apply engine + rollback + UI | v1.4.0 | medium | first version with one-click in-app updates |

### 13.8 Phase 2.5 — settings consolidation

`settings.json` previously conflated three things that wanted different homes: secrets
(`slack_token`), preferences (`interval`, `num_hats`, …), and domain records (`schedules`,
`animals` — already duplicated in the SQLite tables). Phase 2a only did the *interim* fix:
unify the two write paths into one `settings.json` and stop tracking it in git.

Phase 2.5 finished the job — best practice for this project — by giving every category its
proper home:

- preferences → the SQLite DB (`system_settings` table); shipped in **Phase 2.5a (v1.5.0)**;
- the Slack secret → a separate mode-0600, gitignored `secrets.json`; shipped in
  **Phase 2.5b (v1.5.1)**;
- `migrate_settings.py` deleted as dead code (it was never wired in).

Domain records (`schedules`, `animals`) were already in their SQLite tables; the redundant
`setdefault` lines in the old `load_settings` were removed without touching real data flow.

Both phases are non-destructive on upgrade: 2.5a copies legacy `settings.json` values into
the DB on first launch (sentinel prevents re-running); 2.5b moves Slack credentials out of
either the DB (v1.5.0 source) or the legacy JSON (pre-v1.5.0 source) into
`secrets.json` and deletes the DB rows. The legacy file is left intact in both cases.

### 13.9 Phase 3 — signed releases + offline install (DEFERRED)

**Status: deferred until an offline / air-gapped workflow is real.** The online-only update
story is covered by HTTPS to GitHub; minisign's marginal security gain over HTTPS for a
small lab fleet does not justify the maintenance cost. The design below is kept verbatim so
future-you (or a future contributor) can resume in one PR if/when a researcher needs to
update a network-isolated Pi from a USB stick — at that point the offline path makes
signing essential.

Closes the two remaining gaps from §1: supply-chain integrity and air-gapped operation.

**3a — Signed releases + on-device verification (v1.6.0)**

- **Tool:** minisign (Ed25519; small single-binary; in Debian Bookworm apt as `minisign` 0.11).
- **CI signs every bundle.** `release.yml` gains a sign step after the build:
  `minisign -S -s <seckey> -m rrr-X.Y.Z.rrrupdate -x rrr-X.Y.Z.rrrupdate.minisig`. The
  `.minisig` is published as a release asset alongside the bundle and `.sha256`.
- **Device verifies on apply.** `updater.apply_update` downloads the `.minisig` next to the
  bundle, runs `minisign -V -p scripts/release/minisign.pub -m bundle -x sig`, and **rejects
  on mismatch**. Verification runs *after* the SHA256 check, *before* extraction.
- **Permissive on missing signature.** Releases predating v1.6.0 have no `.minisig`; in that
  case apply logs a warning and proceeds — otherwise installing any older release would
  break. From v1.6.0 onwards every release has one, so in practice every OTA is verified.
- **Installer adds `minisign`.** `scripts/install/10-apt.sh` adds the package; an apt update
  reaches it during the v1.6.0 install on existing devices.
- **Key custody:** the secret key lives only in the GitHub Actions secret
  `MINISIGN_SECRET_KEY` (+ `MINISIGN_PASSWORD` if password-protected); the public key is
  checked in at `scripts/release/minisign.pub`. **The maintainer generates the keypair
  locally and never commits the secret.**

**3b — Offline install from USB (v1.6.1)**

- **"Install from file…"** button in `UpdatesTab`.
- `QFileDialog` selects a `.rrrupdate` from anywhere (typically `/media/<user>/<stick>/…`).
- The `.minisig` must be alongside it (same basename + `.minisig`). The same verify path as
  3a applies.
- **Strict on missing signature for offline** (no HTTPS fallback on a USB stick — the
  USB-bundle contract is "must carry both files").
- Engine refactor: `apply_update(info)` and `apply_bundle_from_path(path)` share a private
  `_apply_local_bundle(path, sig_path, expected_sha256=None)` core.

### 14.8 Phase 3 — risk log

- **P1 — Lost private key is unrecoverable.** Losing access to `MINISIGN_SECRET_KEY` means
  burning it from GitHub Actions, generating a new keypair, recommitting the pubkey, and
  forcing every device through an unsigned-or-pre-rotation transition. *Mitigation:* keep a
  paper or password-manager backup of the secret key the moment it is generated.
- **P2 — First signed release (v1.6.0) is not verifiable by older clients.** v1.5.x has no
  verifier; it accepts v1.6.0 over HTTPS without checking. Once a device is on v1.6.0+,
  every subsequent OTA is verified. *Mitigation:* documented; HTTPS is the integrity story
  for that one transition.
- **P3 — Permissive vs strict on missing `.minisig`.** Online apply is permissive (logs a
  warning, accepts), so legacy releases still install. Invalid signatures are always
  rejected. Offline apply is strict (USB has no HTTPS to lean on).
- **P4 — `minisign` binary missing on device.** *Mitigation:* `10-apt.sh` adds the package
  so it lands on every installer run; if the binary is absent at apply time the engine
  errors out clearly rather than silently bypassing verification.
- **P5 — Accidental commit of the secret key.** *Mitigation:* `.gitignore` patterns
  (`*.key`, `minisign.key`) plus a "DO NOT COMMIT" header in the doc.
- **P6 — USB bundle without sig.** Rejected (per P3). Operators are told to copy both files.
- **P7 — minisign CLI behaviour changes across versions.** *Mitigation:* pin via apt
  (Bookworm-pinned 0.11); add a CI step that round-trips `minisign -G/-S/-V` so an upstream
  break shows up before a release.

---

## 14. Phase 2 risk register

Compiled from a code survey *before* implementation. Every risk below has a mitigation that
is now part of the plan.

### 14.1 Findings that correct the Phase 2 plan

- **F1 — `pump_log.json` is a third CWD-relative data file.** `notifications.py` writes
  `LOG_FILE = "pump_log.json"` relative to the working directory (`Project/`). Under
  blue-green the working directory becomes `~/rrr/current/Project`, so this file would land
  *inside the release directory and be lost on every update*. → 2a must also route
  `pump_log.json` through `paths`.
- **F2 — `settings.json` is already split across two files.** `config.py` writes
  `Project/settings/settings.json`; `SlackCredentialsTab.save_credentials` writes
  CWD-relative `Project/settings.json` — a *different file*. → 2a must fix
  `SlackCredentialsTab` to use `paths.settings_path()` **before** any migration, or
  migration copies an incomplete settings file.
- **F3 — 2b is an installer refactor, not just a new module.** `30-python.sh` hard-codes the
  venv at `$REPO_ROOT/.venv` and `50-services.sh` installs `launch.sh` verbatim as the
  launcher. Both must change (venv → `shared/venv`; launcher → thin shim). A standalone
  layout module is not sufficient.
- **F4 — no schema-version mechanism exists.** `create_tables()` does ad-hoc
  `PRAGMA table_info` + `ALTER TABLE` inline. A formal framework would be a *second*
  migration system. Decision: keep `create_tables()` as-is; Phase 2's "migration" support is
  only a `PRAGMA user_version` gate plus the pre-update DB backup — we do **not** rebuild the
  existing ad-hoc migrations.
- **F5 — `Project/migrations/migrate_settings.py` is dead code** (no import site anywhere).
  Flag for removal so it is not confused with the new mechanism.

### 14.2 Data-migration risks (highest severity)

- **R1 — split-brain DB:** app reads the old DB path while migration populated the new one.
  *Mitigation:* `paths` is the single resolver; the launcher always exports `RRR_DATA`;
  migration and runtime resolve identically.
- **R2 — SQLite copied while open → corruption** (live DB has `-wal`/`-shm` sidecars).
  *Mitigation:* migrate with `sqlite3 "$src" ".backup '$dst'"`, not `cp`; only when the app
  is not running.
- **R3 — wrong source DB selected.** *Mitigation:* one deterministic legacy path; if the
  target already exists, skip (idempotent); never guess.
- **R4 — root-owned files in `shared/`** (installer `sudo` steps). *Mitigation:* `shared/` and
  its contents are `chown`ed to the target user; writability asserted post-migration.
- **R5 — destructive migration.** *Mitigation:* copy-not-move; legacy files left intact; a
  timestamped copy also written to `shared/backups/`.

### 14.3 Blue-green / runtime risks

- **R6 — non-atomic symlink swap.** *Mitigation:* create the new link under a temp name then
  `mv -T` (atomic rename); never `rm` then `ln`.
- **R7 — dangling `current`.** *Mitigation:* prune never touches `current`'s target or the
  previous release.
- **R8 — a broken `launch.sh` shipped inside a release** breaks every launch. *Mitigation:*
  keep `launch.sh` minimal and stable; boot-sentinel auto-rollback is the backstop.
- **R9 — the venv is shared, not versioned:** rolling back code does not roll back dependency
  versions. *Mitigation:* deps are pinned and pure-python; re-pip only on a forward update,
  never on rollback; documented limitation.

### 14.4 Apply-engine risks

- **R10 — update applied mid-experiment.** *Mitigation:* hard gate — refuse to apply while a
  delivery worker is running (not a dismissible prompt).
- **R11 — interrupted apply.** *Mitigation:* extract to a temp directory; swap `current` only
  as the final step after the health-check; clean stale temp dirs on the next run.
- **R12 — shallow health-check** (`--selftest` only imports modules). *Mitigation:* accepted;
  the boot sentinel catches runtime failures.
- **R13 — boot sentinel cannot distinguish a crash from a clean quit** (the app exits 0 on a
  normal quit — confirmed in Phase 1 testing). *Mitigation:* the sentinel counts boots that
  *never reached the healthy mark*; the app writes that mark a few seconds after the GUI is
  up, so a clean quit afterwards does not count as a failure.
- **R14 — restart-path ambiguity** (systemd unit vs desktop-icon launch). *Mitigation:*
  `systemctl --user is-active rrr` decides — restart the unit, or instruct the operator.
- **R15 — disk exhaustion** from accumulating releases. *Mitigation:* check free space before
  extracting; prune to 3 releases.

### 14.5 Technical debt accepted

- **D1 — permanent dual path logic** in `paths` (device layout vs dev-clone fallback).
  Necessary; the fallback is kept dead-simple.
- **D2 — two "homes" on a device** (`~/rodRefReg` clone + `~/rrr`). The clone is build-only;
  documented so support is not misled.
- **D3 — installer module ordering** becomes layout-coupled (python → layout → services).
  Documented in each module header.
- **D4 — `requirements_hash` state** must live in `shared/` to decide whether to re-pip.
  A single small state file is the one source of truth.

### 14.6 Phase 2b — implementation risk log

Found while designing the installer refactor; each is mitigated in the 2b code.

- **B1 — root vs user home.** `install.sh` may run under `sudo`; assuming `$HOME` would build
  the tree in `/root`. *Mitigation:* a shared `scripts/install/layout.sh` resolves the target
  user/home via `SUDO_USER` (the pattern `50-services.sh` already uses); the tree is
  `chown`ed to the target user.
- **B2 — venv-path drift.** The venv path is referenced by `30-python`, `40-hardware`,
  `60-verify`, and `launch.sh`. *Mitigation:* `layout.sh` defines `RRR_VENV` once; every
  module consumes it — no path is hard-coded in more than one place.
- **B3 — `--only` / `--skip` runs.** Modules now depend on layout variables. *Mitigation:*
  `layout.sh` is sourced by `lib.sh`, so the variables exist for every module regardless of
  which subset runs.
- **B4 — a re-run corrupts the running release.** *Mitigation:* the bundle is extracted to
  `.incoming-<v>` then atomically `mv`'d into place; the `current` symlink is swapped with
  `mv -T` (atomic rename), never `rm`+`ln`.
- **B5 — migration corruption / live DB.** *Mitigation:* the DB is copied with SQLite's
  online-backup API (`Connection.backup()` via the stdlib — no `sqlite3` CLI dependency),
  consistent even if the DB is open. Copy-not-move; a timestamped copy also goes to
  `shared/backups/`.
- **B6 — re-migration / split data.** *Mitigation:* migration is skipped entirely when
  `shared/data/rrr_database.db` already exists.
- **B7 — `20-repo` refuses a dirty tree.** A device whose clone has local edits will silently
  not update through the installer. *Mitigation:* documented; a device clone is hard-reset to
  the target branch before an installer run. OTA updates (2c) bypass this path entirely.
- **B8 — orphaned pre-2b venv.** The old `~/rodRefReg/.venv` is left behind, unused.
  *Mitigation:* harmless; documented as build-only cruft (relates to D2).
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

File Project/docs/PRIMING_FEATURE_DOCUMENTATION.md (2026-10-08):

# Priming Control Feature - Technical Documentation

## Overview

This document describes the **Priming Control Feature** - a modular, OOP-based system for manual relay control and tube priming in the RRR application.

---

## Table of Contents

1. [Architecture](#architecture)
2. [Design Patterns & Best Practices](#design-patterns--best-practices)
3. [Implementation Details](#implementation-details)
4. [Usage Guide](#usage-guide)
5. [API Reference](#api-reference)
6. [Testing Strategy](#testing-strategy)
7. [Troubleshooting](#troubleshooting)

---

## Architecture

### Component Structure

```
Project/ui/
├── PrimingControlWidget.py    # Standalone priming control widget (NEW)
├── SettingsTab.py              # Settings tab (UPDATED - adds priming tab)
└── ...

Project/drivers/
├── solenoid_controller.py      # Solenoid hardware abstraction
└── ...

Project/gpio/
└── gpio_handler.py             # Low-level relay HAT control
```

### Architecture Diagram

```
┌─────────────────────────────────────────────────────────┐
│                     SettingsTab                         │
│  (Composition: embeds PrimingControlWidget)             │
└────────────────────────┬────────────────────────────────┘
                         │
                         ├── imports & instantiates
                         ↓
┌─────────────────────────────────────────────────────────┐
│              PrimingControlWidget                       │
│  • Modular QWidget for manual control                   │
│  • MVC pattern implementation                           │
│  • Encapsulated hardware logic                          │
└────────────────────────┬────────────────────────────────┘
                         │
                         ├── uses (lazy initialization)
                         ↓
┌─────────────────────────────────────────────────────────┐
│          RelayControlModel                              │
│  • State management (master/cage relays)                │
│  • Observable pattern via Qt signals                    │
│  • Thread-safe operations                               │
└─────────────────────────────────────────────────────────┘
                         │
                         ├── delegates to
                         ↓
┌─────────────────────────────────────────────────────────┐
│  SolenoidController / IndependentSolenoidController     │
│  • Built by build_solenoid_controller (utils/topology)  │
│  • Master + cage relays (no master when independent)    │
└────────────────────────┬────────────────────────────────┘
                         │
                         ├── uses
                         ↓
┌─────────────────────────────────────────────────────────┐
│            RelayHandler                                 │
│  • Low-level relay HAT control                          │
│  • I²C communication                                    │
└─────────────────────────────────────────────────────────┘
```

---

## Design Patterns & Best Practices

### 1. **Separation of Concerns**

- **PrimingControlWidget**: Self-contained UI + control logic
- **RelayControlModel**: State management only
- **SolenoidController**: Hardware abstraction
- **RelayHandler**: Low-level I²C operations

### 2. **Dependency Injection**

```python
# SettingsTab passes dependencies to PrimingControlWidget
priming_widget = PrimingControlWidget(
    settings=self.settings,                      # Injected configuration
    print_callback=self.print_to_terminal,       # Injected logging
    stop_schedule=self._stop_running_schedule,   # Stops a running schedule the way Stop does
)
```
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

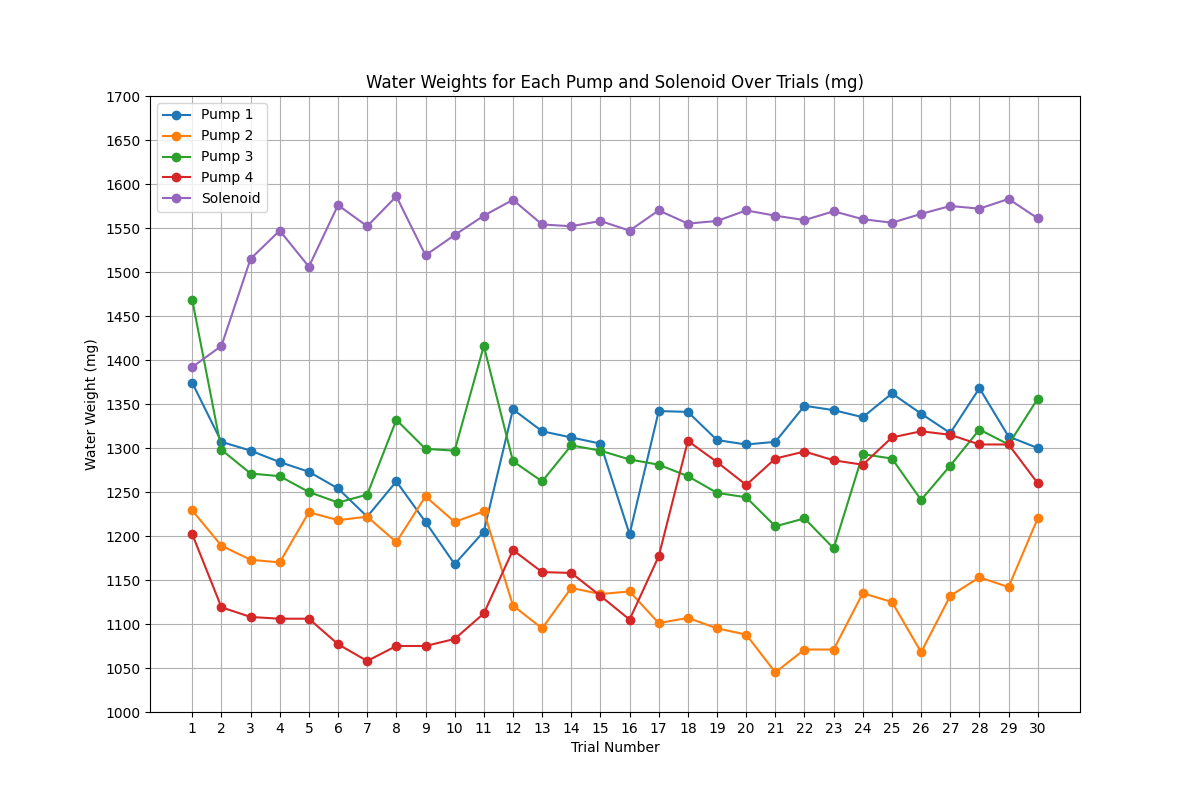
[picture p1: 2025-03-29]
docs/Solenoid_v_Pumps1-3_LineGraph.png

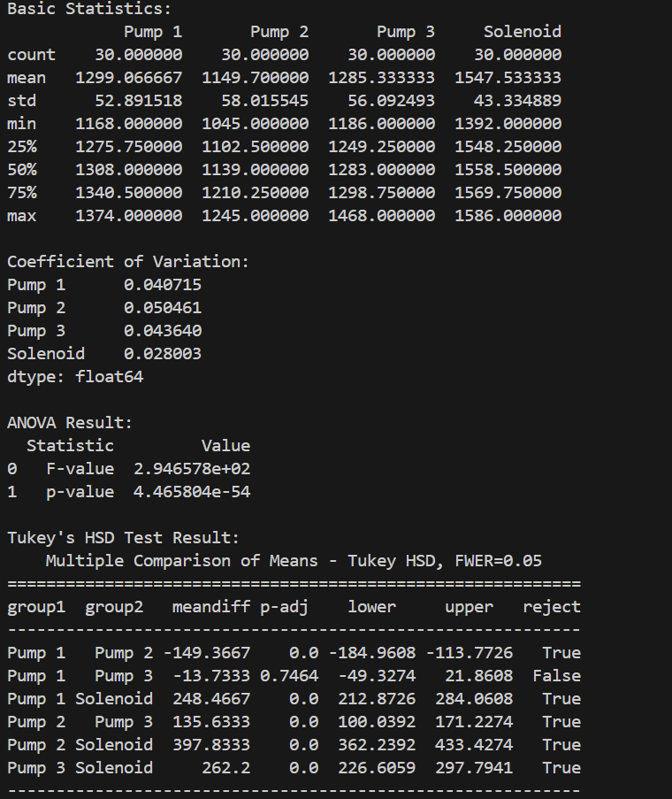
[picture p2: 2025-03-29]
docs/DescriptiveStats_CoeV_Anova_Tukey_for_Solenoid_vs_Pumps1-3.png

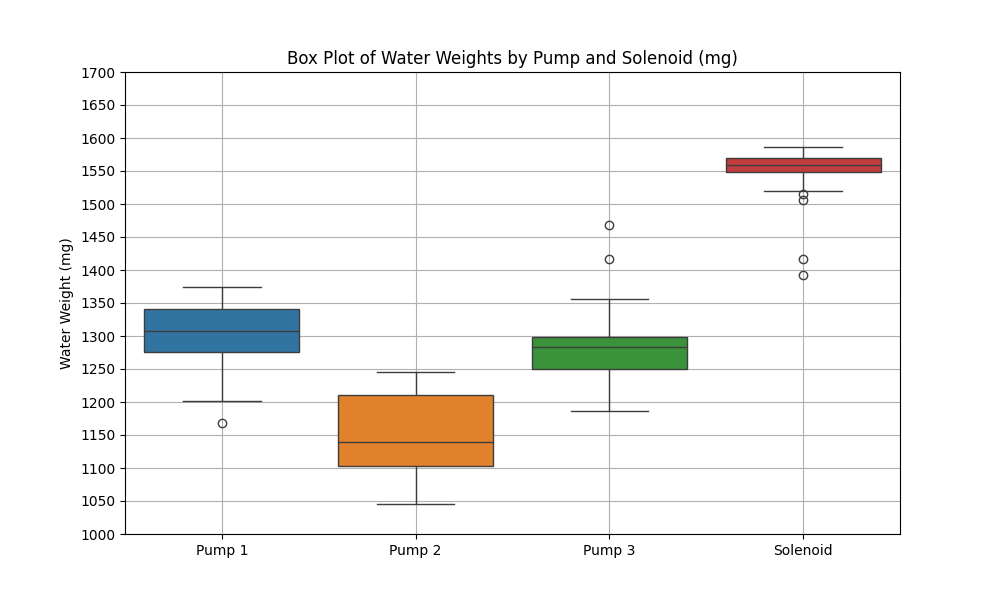
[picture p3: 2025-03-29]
docs/Solenoid_v_Pumps1-3_BoxPlot.png

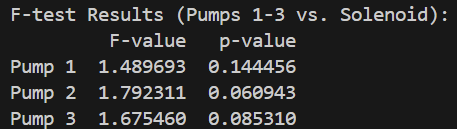
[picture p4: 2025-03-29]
docs/F-value solenoid v pumps.png

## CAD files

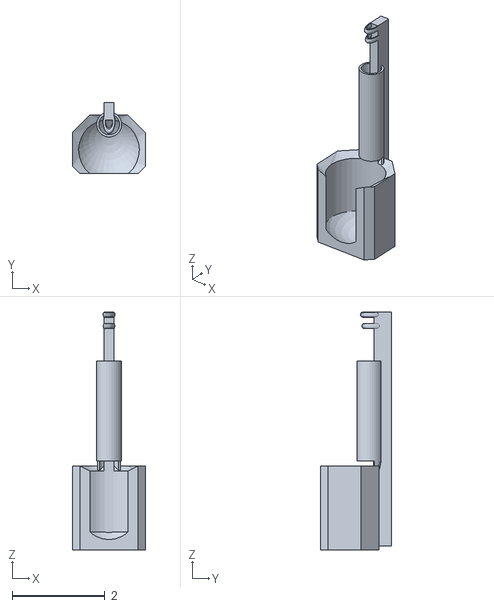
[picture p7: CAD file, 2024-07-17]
Project/docs/STL Files/RRR_Intra_Cage_Water_Collector.stl
1.58 x 1.53 x 5.13

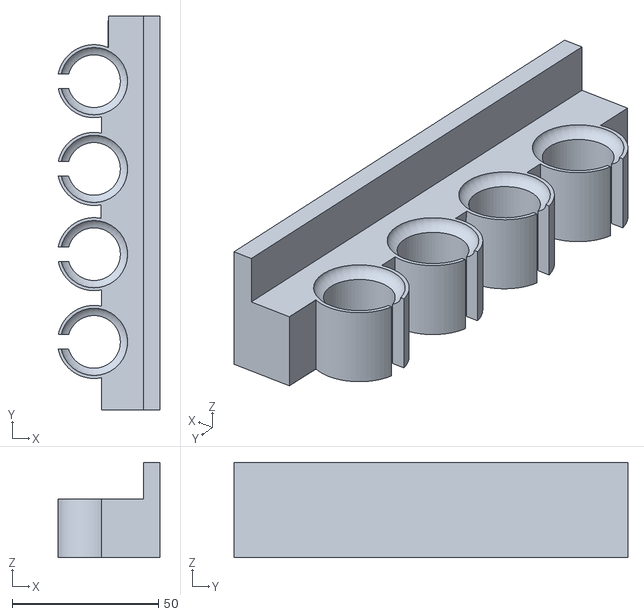
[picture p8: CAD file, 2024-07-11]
Project/docs/STL Files/10ml_Water_Reservoir_Mount_x4.stl
34.7 x 134.7 x 32.6

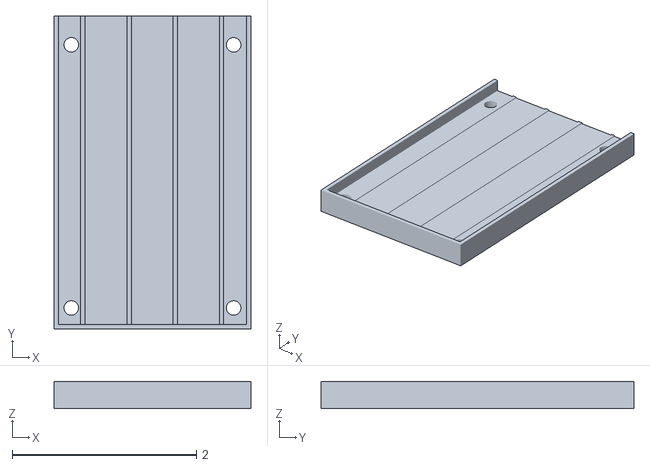
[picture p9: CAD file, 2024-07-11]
Project/docs/STL Files/RRR_Pump_Holder.stl
2.14 x 3.39 x 0.295

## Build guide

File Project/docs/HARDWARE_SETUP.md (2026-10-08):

# Hardware Setup Guide

End-to-end procedure for building an RRR device from parts: Raspberry Pi, relay
HAT, solenoid valves, 12 V DC power, common-ground bus, tubing, and a wall
mount. Written for lab technicians and undergraduate research assistants
without prior electronics experience.

> **Before you start.** Read this document fully once, then execute it
> top-to-bottom on a single bench session. Skipping ahead is the most common
> failure mode. If something does not match what you see in front of you,
> stop and check with a maintainer before applying power.

---

## Contents

1. [Safety](#1-safety)
2. [Bill of Materials](#2-bill-of-materials)
3. [Plan the Installation Before Cutting Wire](#3-plan-the-installation-before-cutting-wire)
4. [Raspberry Pi and Operating System](#4-raspberry-pi-and-operating-system)
5. [16-Relays HAT — Stacking and Jumpers](#5-16-relays-hat--stacking-and-jumpers)
6. [Electrical System — Power and Common Ground](#6-electrical-system--power-and-common-ground)
7. [Valve Wiring](#7-valve-wiring)
8. [Tubing and Reservoir](#8-tubing-and-reservoir)
9. [First Power-On and Bring-Up Test](#9-first-power-on-and-bring-up-test)
10. [Software Install and Verification](#10-software-install-and-verification)
11. [Troubleshooting](#11-troubleshooting)
12. [References](#12-references)

---

## 1. Safety

Solenoid valves, 120 V AC mains, and DC power supplies in close proximity to
water create three risks that you must respect: electric shock, short circuits
through spilled water, and the device latching valves open if it fails wrong.
The procedure below is designed to mitigate each one. Do not deviate.

- **Never apply mains power until every step in
  [§9 First Power-On](#9-first-power-on-and-bring-up-test) is complete.**
- **Keep the 12 V (or 24 V) DC bench supply unplugged from the wall while you
  wire anything.** A multimeter on continuity mode is your friend; an
  energized rail is not.
- **Water and electronics must be separated by a physical barrier.** Mount the
  Pi and HAT above any reservoir or drip path so a leak cannot land on a
  powered board.
- **The DC power supply must be sized for your load.** See
  [§6.2](#62-power-budget). Undersized supplies sag under load and cause valves
  to chatter or fail to open.
- **If you smell burning insulation, see smoke, or a relay LED flickers
  rapidly during quiescent state, disconnect mains immediately.** Diagnose
  cold.
- **Two-person rule for first power-on.** One person at the wall plug, one
  watching the boards. See [§9.1](#91-pre-flight-checklist).

---

## 2. Bill of Materials

Quantities are for a single 15-cage device: 1 HAT × 16 relays gives 15 animal
channels plus relay 16, which is the master valve on the shared-manifold rig
and is left unwired on the independent rig (one syringe and one valve per
animal; see [§7.2](#72-why-the-master-valve-is-on-channel-16)). Scale up for
stacked HATs; each further HAT adds 16 animal channels.

### 2.1 Compute and control

| Item | Qty | Notes |
|---|---|---|
| Raspberry Pi 5 (4 GB or 8 GB) | 1 | Pi 4 also works; this guide targets Pi 5. |
| Raspberry Pi 5 official 27 W USB-C PSU | 1 | Required for Pi 5; under-powered PSUs cause USB resets. |
| microSD card, 32 GB or larger, A2/Class 10 | 1 | Imaged with Raspberry Pi OS Bookworm 64-bit. See [§4](#4-raspberry-pi-and-operating-system). |
| HDMI cable (micro-HDMI to HDMI), USB keyboard, USB mouse, monitor | 1 each | For initial OS setup only. After install you can run headless. |
| Sequent Microsystems *Sixteen Relays 2 A / 24 V 8-Layer Stackable HAT* | 1 (up to 8 stackable) | See bundled [16-RELAYS-UsersGuide](16-RELAYS-UsersGuide_d5e24457-bdd9-4e16-a307-7f90bbd668bb.pdf). |

### 2.2 Solenoid valves

The system is valve-agnostic as long as the valve can be switched by a
single-pole relay rated 2 A at 24 V (the HAT's relay rating). Historical
RRR builds used Parker Series 3 valves; cheaper third-party valves are
currently under evaluation.

| Item | Qty | Notes |
|---|---|---|
| 12 V DC (or 24 V DC) normally-closed solenoid valve, ≤ 2 A holding current, with female 2.1 × 5.5 mm DC barrel-jack pigtail or equivalent leads | Shared manifold: 16 per HAT (1 master + 15 animal). Independent: 15 on the first HAT, 16 on each further HAT (no master) | **TBD — exact model pending lab confirmation.** Confirm voltage matches your PSU. Normally-closed (NC) is required so a power loss closes the valve. |

> **Why 16, not 15? (shared-manifold rig)** The master valve is wired in
> series upstream of the animal valves and provides a single shutoff point.
> Relay channel **16** is the master and channels 1–15 are the animal
> channels — that is the application's default (`global_master_relay_id = 16`
> in [`Project/controllers/system_controller.py`](../controllers/system_controller.py),
> stored per device in the `system_settings` table). Wire to match the
> setting, never the other way round. On an independent rig (one syringe and
> one valve per animal) there is no master: buy 15 valves for the first HAT
> and leave relay 16 unwired (see [§7.2](#72-why-the-master-valve-is-on-channel-16)).

### 2.3 DC power and distribution

| Item | Qty | Notes |
|---|---|---|
| 12 V DC regulated power supply, ≥ 10 A continuous (or 24 V DC if your valves require it) | 1 | **TBD — confirmed amperage pending valve selection.** See [§6.2 Power Budget](#62-power-budget) for the calculation. |
| 1-input × 8-output DC power splitter, 2.1 × 5.5 mm barrel jacks (e.g., Amazon B01H4VEB6G or equivalent) | 2 | One splits PSU → 8 valves; with 16 valves you need two splitters in parallel from the PSU. Verify the splitter's wire gauge supports your total current. |
| Male 2.1 × 5.5 mm DC barrel-jack connectors with screw terminals (e.g., DAYKIT B01J1WZENK or equivalent) | 16 (15 on an independent rig) | One per valve. The valve's two leads land in these connectors. |
| 22 AWG hookup wire, stranded, two colors (red for +12 V, black for ground) | ~5 m each | **Measure your run lengths in [§3](#3-plan-the-installation-before-cutting-wire) before cutting.** |
| Wago lever-nut connectors or equivalent (optional) | as needed | Cleaner than wire nuts for branching the splitter output. |

### 2.4 Common-ground bus

This is the most error-prone subsystem. Read [§6.3](#63-common-ground-bus) in
full before buying parts.

| Item | Qty | Notes |
|---|---|---|
| **Preferred:** DIN-rail grounding terminal block (e.g., Phoenix Contact UT 4 PE or equivalent), or copper bus bar with insulated standoffs | 1 | Purpose-built, safe, and labelable. |
| **Alternative (what we currently use):** 6-outlet surge-protected power strip + 2 × male NEMA 5-15P plug bodies (replaceable plug ends from a hardware store) | 1 strip, 2 plug bodies | See the safety caveats in [§6.3.2](#632-alternative--energized-power-strip-as-ground-bus-current-practice-not-recommended-long-term) — this approach works but ties your DC return to building earth, which has tradeoffs. |
| Solder, heat-shrink tubing, electrical tape | as needed | All wire-to-plug joints must be soldered and insulated. |

### 2.5 Mechanical / mounting

| Item | Qty | Notes |
|---|---|---|
| Wall-mount enclosure or backboard | 1 | **TBD — STL file pending; mount must support the Pi + HAT stack above water level.** |
| 3D-printed reservoir mounts, intra-cage water collectors, pump holders | as needed | STL files in [`Project/docs/STL Files/`](STL%20Files/). |
| Cable ties, adhesive cable mounts, label maker | as needed | Label every wire at both ends before installing. |

### 2.6 Tubing and fluid path

| Item | Qty | Notes |
|---|---|---|
| Food-grade silicone or Tygon tubing | enough for 16 runs | **TBD — confirm inner diameter, outer diameter, material, and length per cage.** Match the tubing ID to your valve's barb fitting. |
| Water reservoir (10 mL per cage mount provided as STL): one shared reservoir on the shared-manifold rig; one syringe per animal on the independent rig | Shared: 1+. Independent: 1 per animal | See [10ml_Water_Reservoir_Mount_x4.stl](STL%20Files/10ml_Water_Reservoir_Mount_x4.stl). |
| Inline barbed fittings, tubing cutter, tube clamps | as needed | |

---

## 3. Plan the Installation Before Cutting Wire

**Do not cut, strip, or solder anything until this step is complete.** A
twenty-minute layout exercise saves hours of rework and a spool of wasted wire.

1. **Locate the wall area where the device will live for the duration of the
   experiment.** This is the mounting surface referenced by the STL backplate
   (TBD — file pending).
2. **Mark the rack/cage positions.** For each animal cage, mark the planned
   location of:
   - The valve body
   - The reservoir
   - The water-delivery spout inside the cage
3. **Measure the longest required run** from the relay HAT to the farthest
   valve, and from that valve to the farthest cage spout. Add 15 % slack for
   service loops at each termination.
4. **Sum the wire runs.** Wire is cheap; running out mid-build is not. Buy
   25 % more than your measured total of each color.
5. **Sketch the layout** (paper is fine). The sketch should show: PSU
   location, splitter location, ground-bus location, every wire run, and every
   tubing run. Photograph the sketch — you will reference it during wiring.
6. **Shared-manifold rig: decide your master-valve location.** The master sits
   between the reservoir and the manifold feeding the animal valves. Wire it to
   relay channel 16 (the application default — see [§7.2](#72-why-the-master-valve-is-on-channel-16)).
   **Independent rig:** there is no master valve and no manifold. Mark each
   animal's syringe location instead, and plan relay 16 as unwired.

---

## 4. Raspberry Pi and Operating System

### 4.1 Flash the OS

1. On any computer, install **Raspberry Pi Imager** from
   <https://www.raspberrypi.com/software/>.
2. Insert the microSD card into your computer.
3. In Imager, choose:
   - **Device:** Raspberry Pi 5
   - **Operating System:** Raspberry Pi OS (64-bit) — *Bookworm*. Do **not**
     choose Lite; the RRR application is a PyQt5 GUI and requires a desktop
     session.
   - **Storage:** the microSD card
4. Click the gear icon (or *Edit Settings*) to pre-configure:
   - Hostname (e.g., `rrr-lab1`)
   - Username and password (avoid the legacy `pi`/`raspberry` default)
   - Wi-Fi SSID and password, or skip if using Ethernet
   - Locale and timezone
   - **Enable SSH** (password authentication is fine on a lab network)
5. Click **Write** and wait for the imager to verify.

### 4.2 First boot

1. Insert the SD card into the Pi 5.
2. Connect HDMI, keyboard, and mouse.
3. Connect the Pi 5's official 27 W PSU **last**.
4. The Pi will boot to a desktop. Open a terminal (top-bar icon).
5. Run a full system update:

   ```bash
   sudo apt update
   sudo apt full-upgrade -y
   sudo reboot
   ```

6. After reboot, verify the OS version:

   ```bash
   cat /etc/os-release | grep VERSION_CODENAME
   # Expected: VERSION_CODENAME=bookworm
   ```

### 4.3 Enable I²C

The relay HAT communicates over I²C. The RRR installer enables this
automatically, but if you want to verify or do it manually:

```bash
sudo raspi-config nonint do_i2c 0
ls /dev/i2c-*           # /dev/i2c-1 must appear
```

---

## 5. 16-Relays HAT — Stacking and Jumpers

The full vendor manual is bundled at
[16-RELAYS-UsersGuide_d5e24457-bdd9-4e16-a307-7f90bbd668bb.pdf](16-RELAYS-UsersGuide_d5e24457-bdd9-4e16-a307-7f90bbd668bb.pdf).
Read it once; the summary below covers only the RRR-specific choices.

### 5.1 Stack-level jumpers (J2)

For a single-HAT build, set **stack level 0** (all three stack-level jumpers
OFF). The HAT responds at I²C address `0x27`. If you stack a second HAT, set
the second board to stack level 1 (jumper 0 ON, jumpers 1 and 2 OFF), address
`0x26`. See pages 6–7 of the vendor manual for the full table.

### 5.2 Other jumpers

- **LED-SEL (rightmost on J2):** Leave at default; switches the on-board LED
  bank between relays 1–8 and 9–16 for visual diagnostics.
- **RS-485 ENB and TERM:** Leave OFF. RRR does not use RS-485 and leaving the
  jumper on holds the Pi's UART, which can interfere with serial debug.

### 5.3 Physical install

1. Pi is powered OFF and unplugged.
2. Install the four M2.5 × 19 mm standoffs in the Pi's mounting holes (nuts
   on the underside).
3. Seat the HAT firmly onto the Pi's 40-pin GPIO header. The header pins
   should disappear fully into the HAT's socket — a partial seat is the most
   common reason for "HAT not detected".
4. Secure with the four M2.5 × 5 mm screws into the standoffs.
5. **Do not connect the HAT's auxiliary +5 V terminal block yet.** The Pi
   powers the HAT logic over the GPIO header for bring-up; the auxiliary
   power is only needed if you want to power the Pi *from* the HAT's terminal
   (we do not).

---

## 6. Electrical System — Power and Common Ground

This section is the part most likely to go wrong. Wire it slowly, label
everything, and use a multimeter to verify continuity before applying power.

### 6.1 Topology overview

```
                              ┌──────────────────────┐
                              │   12 V DC PSU        │  (wall plug)
                              │   ≥ 10 A regulated   │
                              └─────────┬────────────┘
                                        │  (DC barrel out)
                                        ▼
                              ┌──────────────────────┐
                              │  1×8 DC splitter ×2  │  (8 outputs each = 16 total)
                              └─────────┬────────────┘
                                        │  (one barrel-jack per valve)
                                        ▼
                              ┌──────────────────────┐
   Relay HAT COM (per relay)──┤      Each valve      │
                              │   (+12 V from        │
                              │   splitter, switched │
                              │   by relay)          │
                              └─────────┬────────────┘
                                        │  (valve return)
                                        ▼
                              ┌──────────────────────┐
                              │  Common Ground Bus   │ ◄── Relay HAT GND
                              │  (§6.3)              │ ◄── PSU return
                              └──────────────────────┘
```

### 6.2 Power budget

Compute total current before choosing a PSU:

```
I_total = N_valves × I_per_valve_holding_current
        + I_Pi_5         (≈ 5 A peak on its own 5 V rail — separate supply)
        + I_HAT_logic    (≈ 10 mA, negligible)
```

For 16 valves at, say, 250 mA holding current each: `I_total = 16 × 0.25 = 4 A`.
A 10 A 12 V supply gives 2.5× headroom, which is the minimum for inductive
loads (valves) where inrush can briefly hit 2–3× holding current.

> **TBD.** Confirm the per-valve holding current from the valve datasheet
> before ordering the PSU.

### 6.3 Common-ground bus

Every DC return in the system — the relay HAT's GND pin, the PSU's negative
output, and every valve's return lead — must meet at a single physical point.
This is the **common ground**. Without it, relays either do not switch or
chatter, and the Pi can latch up.

#### 6.3.1 Preferred — DIN-rail terminal block or copper bus bar

1. Mount a single ground terminal block (e.g., Phoenix Contact UT 4 PE) on a
   short section of DIN rail attached to your backboard.
2. Run a single 18 AWG wire from the PSU's negative terminal to one slot.
3. Run a single 22 AWG wire from the relay HAT's GND header pin (any GND
   pin on the Pi 5 GPIO header, since the HAT shares it) to another slot.
4. Run every valve-return wire to its own slot (one per slot): 16 on the
   shared-manifold rig, 15 on the independent rig.
5. Label every slot. Take a photo.

This is electrically clean, mechanically tidy, and the obvious first thing a
future maintainer will understand.

#### 6.3.2 Alternative — energized power strip as ground bus (current practice, not recommended long-term)

This is the technique currently in use on existing RRR builds. It works, but
it has caveats that make the [§6.3.1](#631-preferred--din-rail-terminal-block-or-copper-bus-bar)
approach strictly better for new installs.

**What it does:** All DC return wires are soldered to the **ground (earth)
pin** of a male NEMA 5-15P plug body. The plug is inserted into a standard
6-outlet power strip whose ground bar internally joins every outlet's ground
pin and ties them to building earth via the wall outlet's third prong.

**Why it works:** Building earth is, by code, a low-impedance reference that
all DC returns can share. The power strip simply rents you a copper bar that
happens to already be wired to earth.

**Why it is risky:**

1. **You are tying your DC return to building earth at one specific point.**
   If anything else in your fluid path (a metal reservoir, a grounded sensor,
   a USB connection to a grounded laptop) is *also* tied to earth elsewhere,
   you have a ground loop. Ground loops cause noise on sensor reads and, in
   pathological cases, current flow through unintended paths.
2. **The hot and neutral pins of the plug body MUST be left unconnected and
   physically insulated.** A loose strand of solder bridging the ground pin
   to neutral energizes your entire DC return at 120 V AC. This will destroy
   the Pi, the HAT, and every valve, and present a shock hazard.
3. **The power strip must be plugged into a properly wired three-prong
   outlet** with a verified ground. Cheap outlet testers from any hardware
   store will confirm this.
4. **A soldered breadboard ground rail is NOT a substitute.** We tried it;
   the rail current capacity was insufficient for the combined valve return
   currents and produced intermittent valve behavior.

**Procedure if you must use this approach:**

1. Buy two male NEMA 5-15P replacement plug ends from any hardware store
   (Home Depot, Walmart, etc.). They unscrew to expose three terminals
   labeled HOT, NEUTRAL, and GROUND.
2. **Plug 1 (PSU side):** Solder together the PSU negative lead, the relay
   HAT GND lead, and any other "power-supply-side" returns. Heat-shrink the
   joint. Strip ~10 mm of one end and secure it under the GROUND screw of
   the plug body. Verify HOT and NEUTRAL terminals are empty and the screws
   are tight against the empty terminal so they cannot work loose. Reassemble
   the plug body.
3. **Plug 2 (valve side):** Same procedure with every valve return lead (16 on
   the shared-manifold rig, 15 on the independent rig) joined to a single lead
   going to the GROUND pin.
4. Plug both into the same power strip. The power strip's ground bar joins
   the two plug-side return bundles.
5. Plug the power strip into a verified-grounded wall outlet.
6. **Before applying DC power**, use a multimeter on continuity mode to
   verify:
   - Continuity between plug 1's GROUND pin and plug 2's GROUND pin (should
     beep through the power strip).
   - **No continuity** between either plug's GROUND pin and either plug's
     HOT or NEUTRAL pin. If you hear a beep, stop and rebuild — you have a
     short.

**Migration plan.** If your current build uses the power-strip technique, it
is safe to keep running, but the next time you have the device on the bench
for any other reason, swap to a DIN-rail terminal block per
[§6.3.1](#631-preferred--din-rail-terminal-block-or-copper-bus-bar). It is a
30-minute job and removes all of the caveats above.

---

## 7. Valve Wiring

Wire one valve end-to-end and bring it up before wiring the rest. Catching
a wiring error on valve 1 is a five-minute fix; catching it after wiring all
16 is two hours.

### 7.1 Per-valve wiring

For each valve, in order from relay channel 1 through channel 15 (animal
channels) and then, on the shared-manifold rig only, channel 16 (master). On
the independent rig leave channel 16 unwired:

1. **Identify the relay channel's NO and COM terminals** on the HAT's
   pluggable terminal block. NO is "normally open" (the side the valve sees
   only when the relay activates). COM is "common" (always connected to the
   downstream side of the relay). Pairs of two relays share a COM pin — see
   the board-layout diagram on page 6 of the vendor manual.
2. **Run a wire from one output of the DC splitter to the COM terminal of
   this relay channel.** This carries +12 V from the PSU through the splitter
   to the relay's input side. Use red wire.
3. **Run a wire from the relay's NO terminal to one lead of the valve.** Use
   red wire. Terminate it in the male barrel-jack connector that mates with
   the valve's pigtail.
4. **Run a wire from the valve's other lead to the common ground bus** (per
   [§6.3](#63-common-ground-bus)). Use black wire.
5. **Label both ends of every wire** with the channel number (e.g., `R03+`
   and `R03-` for relay 3).

### 7.2 Why the master valve is on channel 16

On the shared-manifold topology (the default) the master is software-treated
as a global shutoff: the application opens it before any animal valve and
closes it after the last one in every delivery and calibration run, and in
the Priming tab a cage valve opens only while the master is open. On the
independent topology (below) RRR never drives it. Channel 16 is the default
master: `global_master_relay_id = 16` in
[`Project/controllers/system_controller.py`](../controllers/system_controller.py),
stored per device in the `system_settings` table. The cage map skips that one
relay, so a single HAT gives 15 animal channels (1–15); a second HAT adds 16
more (relays 17–32 are all animal channels — the master is global, not per
HAT). Remap only if you have a hardware reason to, and change the setting
before you rewire: `SolenoidController` takes the id from the setting and has
no default of its own.

> **Independent setup (one syringe and one valve per animal, no manifold, no
> master).** From v1.21.0 the valve topology is chosen in RRR: log in, open
> **Settings → Delivery → Valve Topology** (in *Solenoid Mode Settings*, shown
> while Hardware Mode is *Solenoid*), click **Independent (one syringe and one
> valve per animal)** and confirm. The choice is greyed out, and refused with
> *Cannot Change Topology*, while a schedule, a priming session or a
> calibration is running. Confirming the change (**Restart RRR**; **Cancel**
> keeps the old one) restarts RRR, so priming, calibration and schedules all
> use the new topology; log in again afterwards. If RRR cannot restart itself
> it says so: close and reopen RRR before priming. RRR records who made the
> change, and when, in its database (the `logs` table, action
> `valve_topology`), and prints a `[TOPOLOGY] Valve topology changed in
> Settings: …` line with the user's name just before it restarts (under
> `rrr.service` the line is in the journal).
>
> With the app closed (its window, or `systemctl --user stop rrr.service`
> where it runs as the user service), the command-line tool does the same,
> without the `logs` record:
>
> ```bash
> cd ~/rrr/current/Project
> ~/rrr/shared/venv/bin/python3 tools/set_valve_topology.py independent --yes
> ~/rrr/shared/venv/bin/python3 tools/set_valve_topology.py   # prints: current valve_topology: independent
> ```
>
> and then start the app again. The tool prints the database it is acting
> on, never creates one, and refuses to write while it can see the app
> running (a running app would save its old value back over the new one).
> On the independent topology the Priming tab shows no master-valve controls.
> Deliveries pulse the cage valve only, with no manifold prime, and relay
> 16 is never driven. It is, however, still **reserved** in this release —
> an independent rig gets 15 animal channels on the first HAT (and 16 on
> each additional HAT, since only relay 16 is reserved), and channel 16
> should stay unwired until a later release lifts the reservation.
>
> On a release before v1.21.0, or before the setting is applied, the
> shared-manifold code energises relay 16 for the **whole** of every
> delivery (a 200 ms prime, then held open across every pulse — seconds to
> tens of seconds depending on the interval), for the whole of a calibration
> run, and in the priming tab from Open Master until Close Master. So on a
> rig without a master valve, leave channel 16 unwired. Every other step in
> this guide applies, following its notes for the independent rig: one relay
> per animal valve, one syringe per animal.
>
> Never set `independent` on a rig that has a master valve: the master would
> never open and every delivery would be logged as a full dose while the
> animal received nothing.
>
> After switching, calibrate every animal channel in **Settings →
> Calibration**. A calibration measured under the other valve topology shows
> **Stale** there (one saved before v1.21.0 counts as shared manifold). In
> solenoid pulse mode (the default) **Run** refuses a schedule that waters a
> cage with no usable calibration measured under this device's valve
> topology (*Valve calibration needed*), so a Stale cage cannot be watered
> until it is recalibrated. **Calibrate All Uncalibrated** takes the Stale
> and Invalid cages as well as the uncalibrated ones.

### 7.3 Verify before powering

With the DC supply **still unplugged from the wall**:

- Every valve return lands on the common ground bus (visual inspection).
- Every relay COM has +12 V wired in (from a splitter output).
- No exposed conductors anywhere. Heat-shrink or insulating cap on every
  joint.
- The HAT is fully seated on the Pi's GPIO header.

---

## 8. Tubing and Reservoir

> **TBD — exact tubing specifications pending lab confirmation.** Update this
> section with the chosen inner diameter, outer diameter, material, and the
> per-cage length once the lab settles on a part.

General guidance:

1. **Shared-manifold rig:** mount the reservoir(s) above the highest valve.
   Gravity feed simplifies priming and prevents the master valve from running
   dry. **Independent rig:** mount each animal's syringe above its valve and
   note its fill level (whether the level changes the dose is still being
   measured; see [TOPOLOGY_VALIDATION.md](TOPOLOGY_VALIDATION.md) C8).
2. Cut tubing per fluid path, using the layout sketch from
   [§3](#3-plan-the-installation-before-cutting-wire). **Shared manifold:**
   reservoir → master valve → manifold → each animal valve → each cage spout.
   **Independent:** each syringe → its animal valve → its cage spout.
3. Use barbed fittings sized for your tubing's inner diameter. Push the
   tubing fully onto the barb; secure with a small zip tie or clamp if your
   delivery pressure exceeds gravity-fed.
4. Prime the lines before first delivery via **Settings → Priming** in the
   RRR application. See [PRIMING_FEATURE_DOCUMENTATION.md](PRIMING_FEATURE_DOCUMENTATION.md).
5. Inspect every joint for leaks after priming. A drip on a powered HAT will
   end your day.
6. **Independent rig:** check every syringe line daily; a primed line holds
   about three days, so prime again any line left idle over a long weekend
   before its animal depends on it.

---

## 9. First Power-On and Bring-Up Test

### 9.1 Pre-flight checklist

Verify each item; do not power on until all are checked.

- [ ] [§3](#3-plan-the-installation-before-cutting-wire) layout sketch
      matches what is on the wall.
- [ ] [§4](#4-raspberry-pi-and-operating-system) Pi boots to desktop and
      `/dev/i2c-1` exists.
- [ ] [§5](#5-16-relays-hat--stacking-and-jumpers) HAT seated, stack-level
      jumpers set, RS-485 jumpers OFF.
- [ ] [§6.3](#63-common-ground-bus) common ground bus continuity verified
      with multimeter; no short between ground and 12 V.
- [ ] [§7](#7-valve-wiring) every valve wired, labelled, insulated: 16 per HAT
      on the shared-manifold rig (15 animal + master on relay 16); on the
      independent rig 15 on the first HAT with relay 16 left unwired.
- [ ] [§8](#8-tubing-and-reservoir) tubing routed, reservoir (or every
      syringe) mounted, but **empty** for first bring-up.
- [ ] Two people present: one at the wall plug, one watching the boards.

### 9.2 Power-on sequence

Apply power in this order. Pause between each step and watch for smoke,
unexpected LEDs, or anything getting warm.

1. Plug in the Pi 5's USB-C PSU. Pi boots to desktop.
2. Plug in the 12 V DC supply (still no water). Relay HAT's power LED
   illuminates. **No relay LEDs should be on** in this quiescent state. If
   any are, the wiring has a short — disconnect immediately and recheck.
3. Open a terminal on the Pi and verify the HAT:

   ```bash
   sudo i2cdetect -y 1
   # Expected: device responds at 0x27 (stack level 0)
   ```

4. Click each relay individually using the vendor CLI (the RRR installer
   sets this up; for a pre-install dry run, follow the vendor manual's
   software setup section). With no water in the system, a successful click
   should:
   - Light the relay's status LED
   - Produce an audible click from the valve
   - Light extinguishes and valve clicks back when relay is released

5. If every wired relay clicks its valve cleanly (on the independent rig
   relay 16 has no valve: its LED lights and nothing else happens), fill the
   reservoir (or the syringes) and proceed to
   [§10](#10-software-install-and-verification).

---

## 10. Software Install and Verification

Once the hardware passes [§9](#9-first-power-on-and-bring-up-test), install
the RRR application:

```bash
curl -fsSL https://raw.githubusercontent.com/Corticomics/rodRefReg/main/bootstrap.sh | bash
```

The installer enables I²C, installs the relay HAT driver, sets up a systemd
user service, and verifies every dependency. Full install details, flags,
and headless operation are in the [project README](../../README.md).

After install:

1. **Launch the application** from the desktop icon or `~/.local/bin/rrr`.
2. **Set the valve topology** to match the plumbing: log in, open
   **Settings → Delivery → Valve Topology** and choose **Shared manifold
   (master valve)** (the default) or **Independent (one syringe and one valve
   per animal)**. Do this before priming and calibrating: each calibration
   records the topology it was measured under, and one measured under the
   other valve topology shows **Stale**. Confirming a change restarts RRR.
3. **Open Settings → Priming** and prime every line. See
   [PRIMING_FEATURE_DOCUMENTATION.md](PRIMING_FEATURE_DOCUMENTATION.md).
4. **Calibrate every valve.** See [CALIBRATION_QUICK_START.md](CALIBRATION_QUICK_START.md).
   This step is mandatory: in solenoid pulse mode (the default) **Run**
   refuses a schedule that waters a cage with no usable calibration measured
   under this device's valve topology (*Valve calibration needed*), because
   RRR cannot know how much water a pulse gives without one.
5. **Run a 0.5 mL test schedule** on a single cage and weigh the output to
   confirm calibration accuracy is within ±5 %.

---

## 11. Troubleshooting

| Symptom | First thing to check |
|---|---|
| HAT not detected (`i2cdetect` shows nothing at 0x27) | HAT fully seated on GPIO header; stack-level jumpers correct; `/dev/i2c-1` present; user in `i2c` group (`groups $USER`). |
| Relay clicks but valve does not open | +12 V present at COM terminal under load (measure with multimeter while relay is active); valve return reaches common-ground bus; PSU not sagging. |
| Multiple valves open when only one is requested | Common-ground continuity is bad; a relay's NO and another relay's COM are shorted; rewire and re-verify [§7.3](#73-verify-before-powering). |
| Relay LEDs flicker rapidly at idle | Wiring short between +12 V and ground somewhere; disconnect mains immediately and trace with a multimeter on continuity. |
| Pi reboots when valves activate | PSU undersized or the Pi is sharing power with the valve rail. Pi 5 must be on its own 27 W USB-C PSU; valves on their own 12 V supply. |
| Sensor noise / erratic flow readings | Likely ground loop. Check [§6.3.2 caveat 1](#632-alternative--energized-power-strip-as-ground-bus-current-practice-not-recommended-long-term). |
| **Run** shows *Valve calibration needed* or *Cage not on this device* and the schedule does not start | A cage the schedule waters has no calibration, one marked **Invalid** (volume per pulse or pulse width missing, zero or invalid), or one marked **Stale** (measured under the other valve topology; one saved before v1.21.0 counts as shared manifold); or the schedule names a cage this device does not have. Calibrate the listed cages in **Settings → Calibration** (or edit the schedule), then press **Run** again. See [CALIBRATION_QUICK_START.md](CALIBRATION_QUICK_START.md). |
| Delivered volume is well off target | The cage's calibration no longer matches its valve or line (a valve, tubing, needle or supply change, or air in the line): prime the line, recalibrate that cage per [CALIBRATION_QUICK_START.md](CALIBRATION_QUICK_START.md), and weigh a test dose. With **Enable Pulse Mode** off (RRR turns it back on each time it starts), deliveries use no calibration: the valve is timed from an expected flow rate, or closed on the flow sensor's reading when one is fitted. |
| Terminal tab shows `[VALVE ERROR] cage N: … did not reach its relay; delivery stopped`, and the ledger shows `failed` / `partial` rows | A relay write did not reach its HAT: a HAT that was not found at start-up, a relay on a HAT that is missing, or an I²C error. From v1.21.0 the delivery stops there instead of counting the pulse. Only pulses whose valve opened are credited (a pulse whose close got through only on a retry is credited with the time its valve stayed open), and the retry 30 s later asks for the rest. A pulse that fails for any other reason also ends the delivery (`[VALVE ERROR] cage N: pulse K failed: …`). Check `i2cdetect -y 1` and run the bring-up test in [§9](#9-first-power-on-and-bring-up-test). RRR sets the HATs up only when it starts, so after fixing a HAT that was missing, **close and reopen RRR**; until then every delivery to it keeps failing. If deliveries keep failing, the schedule stops ("Deliveries kept failing: check the relay HAT … and the flow sensor"). |
| `[VALVE CRITICAL] … OPEN` (for pump relays, `… ON`), **Emergency Stop Failed** or **Relays Not Confirmed Off** | A close, or the all-relays-off command, did not reach a HAT, or a valve's relay has not answered since the run started, so that valve may still be open. **Disconnect the valve power supply first**, then check the relay HAT and its I²C connection as above. **Settings → Priming → CLOSE ALL RELAYS** switches every relay off again and stops a running schedule. The schedule does not resume: Run starts it over (staggered: every animal's whole dose again; instant: delivery times that have passed are skipped), so check what each animal has received (the Terminal tab, or `tools/gravimetric_check.py daily`) before running it again. When a later close gets through, the Terminal tab shows `[VALVE OK] The cage N valve closed after all; …`. |
| Water leaking onto HAT | Power off immediately. Dry fully (24 h, no heat). Inspect for corrosion on terminals before re-powering. |

---

## 12. References

- [16-RELAYS Vendor User's Guide](16-RELAYS-UsersGuide_d5e24457-bdd9-4e16-a307-7f90bbd668bb.pdf)
  — Sequent Microsystems, version 1.0
- [Raspberry Pi 5 documentation](https://www.raspberrypi.com/documentation/computers/raspberry-pi-5.html)
- [Raspberry Pi OS Bookworm release notes](https://www.raspberrypi.com/news/bookworm-the-new-version-of-raspberry-pi-os/)
- [CALIBRATION_QUICK_START.md](CALIBRATION_QUICK_START.md) — per-valve
  calibration procedure (run after hardware build).
- [VALVE_CALIBRATION_GUIDE.md](VALVE_CALIBRATION_GUIDE.md) — technical
  reference behind the calibration wizard.
- [PRIMING_FEATURE_DOCUMENTATION.md](PRIMING_FEATURE_DOCUMENTATION.md) —
  priming sequence and safety interlocks.
- [DEVELOPMENT.md](DEVELOPMENT.md) — software architecture (for developers
  extending the system).
- [MAINTENANCE.md](MAINTENANCE.md) — release and update procedures.

---

## Items pending lab confirmation (TBD)

The following are flagged in-line above. Update this list as decisions are
made:

- [ ] Solenoid valve make and model (currently evaluating cheaper alternatives
      to Parker Series 3).
- [ ] Per-valve holding current, used in [§6.2 Power Budget](#62-power-budget).
- [ ] 12 V vs. 24 V DC PSU (depends on chosen valve).
- [ ] Exact PSU make and model with confirmed continuous current rating.
- [ ] Wall-mount backplate STL file (referenced in
      [§2.5](#25-mechanical--mounting) and [§3](#3-plan-the-installation-before-cutting-wire)).
- [ ] Tubing inner diameter, outer diameter, material, per-cage length
      (referenced in [§2.6](#26-tubing-and-fluid-path) and [§8](#8-tubing-and-reservoir)).

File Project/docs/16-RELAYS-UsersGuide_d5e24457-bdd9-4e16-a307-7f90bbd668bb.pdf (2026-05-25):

16-RELAYS for RASPBERRY PI

USER'S GUIDE VERSION 1.0

SequentMicrosystems.com

### GENERAL DESCRIPTION

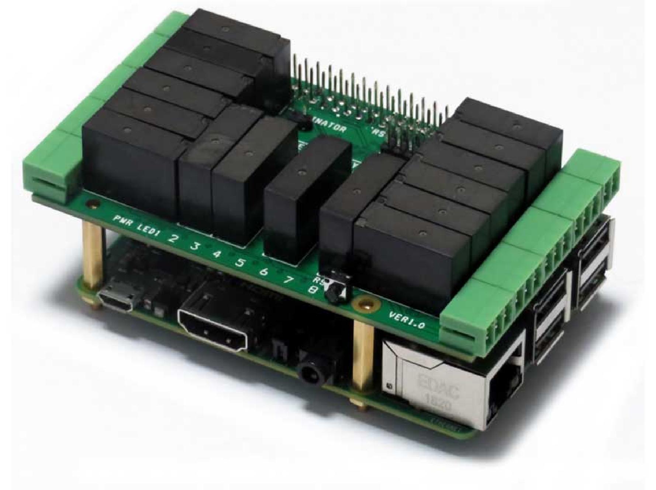
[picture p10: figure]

The 16-RELAYS card is a stackable expansion card for Raspberry Pi. The card is compatible with all Raspberry Pi versions from Zero to 4. It offers a compact and inexpensive solution for adding up to 128 relays to your Raspberry Pi project.

Pluggable connectors make the 16-RELAYS card easy to use when multiple cards are stacked up. Loads of up to 2.5A and 24V can be switched by all relays. Status LEDs show when relays are on or off.

Each relay has a corresponding LED installed on the long side of the card which turns on when the relay is energized. A LED also shows when power is applied to the board. A pushbutton permits the user to issue a command to Raspberry Pi or to shut it down (a script is required for the desired application). Since the long side of the board has room for only 8 status LEDs, a jumper selects to display the status of the left or right relay banks.

The 16-RELAYS card has also an RS485 driver which can enables the Raspberry Pi to communicate with other industrial equipment using the MODBUS protocol.

Mechanically, the 16-RELAYS card adheres to the Sequent Microsystems Modular Industrial format. It can be installed in the free 3D printable stackable enclosure. All the cards in this format have the same mechanical specifications.

### FEATURES

- Sixteen Relays with Status LEDs
- Pluggable Connectors, 26-16 AWG wires
- All Relays with NO and COM Contacts, rated 2.5A/24VAC or DC
- RS485 Port with TVS protection
- Reverse polarity power supply protection
- General purpose pushbutton
- All mounting hardware included: stand-offs, screws and nuts
- Software self-test
- Command Line, Node-RED, Python and OpenPLC Drivers

Up to eight 16-RELAYS cards can be stacked on top of one Raspberry Pi. The 16-RELAYS cards share a serial I2C bus using only two of the Raspberry Pi’s GPIO pins to manage all eight cards. This feature leaves the remaining 24 GPIOs available for the user.

### WHAT IS IN YOUR KIT

1. 16-RELAYS Card for Raspberry Pi

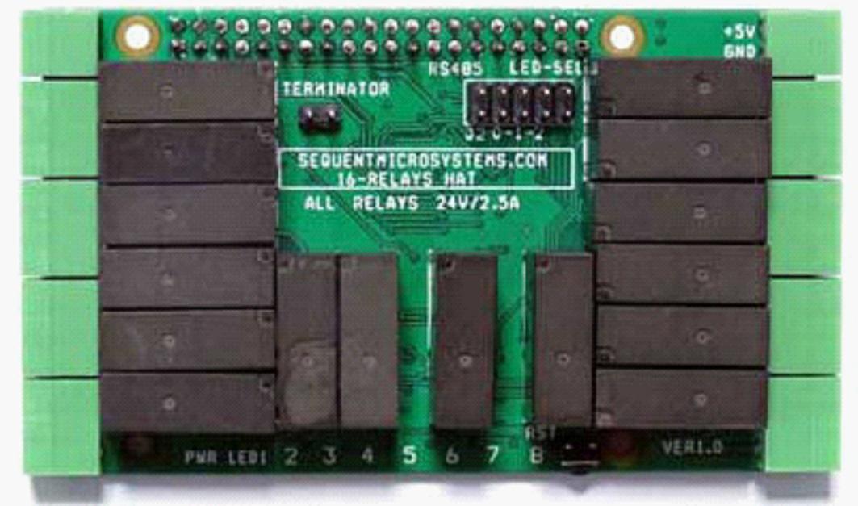
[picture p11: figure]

2. Mounting hardware:
a. Four M2.5x19mm male-female brass standoffs
b. Four M2.5x5mm brass screws
c. Four M2.5 brass nuts

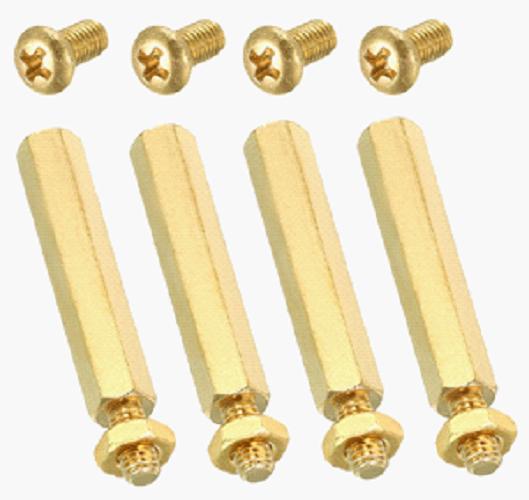
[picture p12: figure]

3. Two jumpers.
4. All the required female mating connectors.

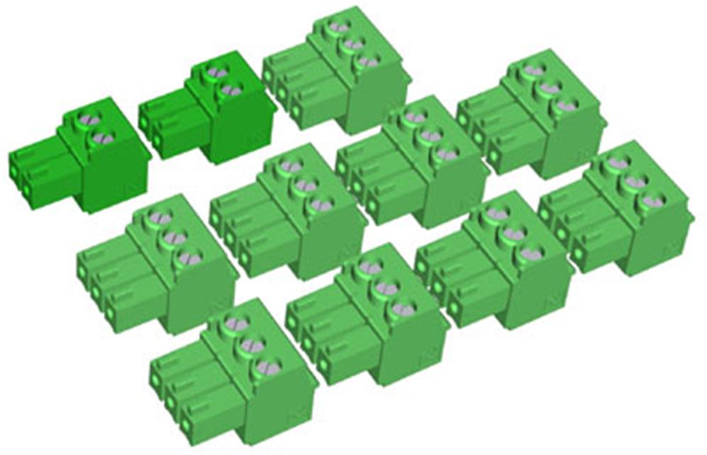
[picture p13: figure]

### QUICK START-UP GUIDE

1. Plug your 16-RELAYS card on top of your Raspberry Pi and power up the system.
2. Enable I2C communication on Raspberry Pi using raspi-config.
3. Install the 16-RELAYS software from github.com:
a. ~$ git clone https://github.com/SequentMicrosystems/16relind-rpi.git
b. ~$ cd /home/pi/16relind-rpi
c. ~/16relind-rpi$ sudo make install
4. ~ $ 16relind

The program will respond with a list of available commands.

### BOARD LAYOUT

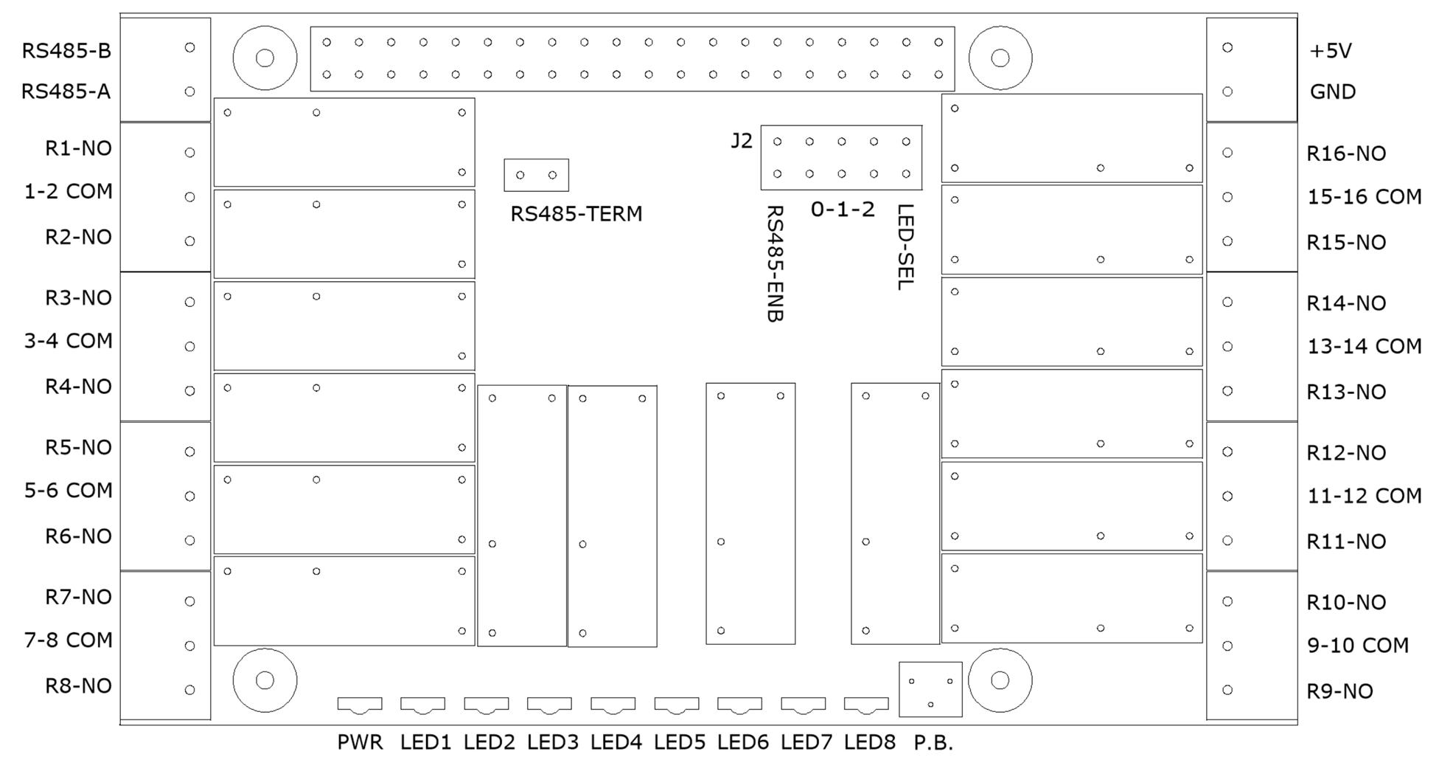
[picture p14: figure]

Your 16-RELAYS card comes with appropriate mounting hardware. Up to eight 16-RELAYS cards can be stacked on top of one Raspberry Pi. Eight LEDs indicate the status of their respective relay. An LED is lit when the corresponding relay is energized. The General Purpose Pushbutton GPB is connected to pin 37 of the Raspberry Pi GPIO connector (GPIO26). In order to use the pushbutton you need to write a shell script to accomplish the desired function.

All relays have NO and COMMON contacts brought out to pluggable connectors. Pair of 2 relays share the COMMON pin.

The right-most position of the J2 jumper selects which bank of relays displays the status on the LEDs. The next three positions are used for selecting the stack level (see next section). The left position is used for the RS485 port. The port is driven by the serial pin of Raspberry Pi. Install the jumper if you want to use the RS485 port. Remove the jumper if the serial port of Raspberry Pi is used for another purpose.

### STACK LEVEL SETTINGS

Up to eight 16-RELAYS Cards can be installed on top of one Raspberry Pi. The 16-RELAYS Card shares the same I2C address with the 8-INPUTS, 8-MOSFETS, 8-RELAYS AND 16-INPUTS cards. If a combination of these cards is used in the same stack, a total of eight cards can be installed.

The 16-RELAYS card is controlled by Raspberry Pi using only the I2C interface. The card occupies the address space 0x20 - 0x27. The local address can be configured using the Stack Level Jumpers or DIP switches. A maximum stack of eight cards requires a total of 12 jumpers.

Cards can be installed on Raspberry Pi in any order. The 3 position jumper or DIP switch is selecting the stack level of the card, as follows:

JMP/SW | | OFF | OFF | OFF | | ON | OFF | OFF | | OFF | ON | OFF | | ON | ON | OFF
STACK LEVEL | 0 | | | | 1 | | | | 2 | | | | 3
I2C ADDR. | 0x27 | | | | 0x26 | | | | 0x25 | | | | 0x24
JMP/SW | | OFF | OFF | ON | | ON | OFF | ON | | OFF | ON | ON | | ON | ON | ON
STACK LEVEL | 4 | | | | 5 | | | | 6 | | | | 7
I2C ADDR. | 0x23 | | | | 0x22 | | | | Ox21 | | | | Ox20

To find out the stack level of all the cards installed in your system run the command line with the “-list” option.

### OpenPLC SETUP

When using OpenPLC only two 16-RELAYS Cards can be accessed in one system, on stack levels 4-5.

The stack level 0-3 is reserved for the 8-RELAYS and stack level 6-7 reserved for 16-INPUTS Cards.

### RS-485 COMMUNICATION

The 16-RELAYS cards card contains a standard RS485 transceiver which can be accessed by the serial port of the Raspberry Pi. In order to enable communication, the jumper labeled RS485EN on J2 connector needs to be installed.

### POWER REQUIREMENTS

The 16-RELAYS card requires +5V power, supplied either from the Raspberry Pi expansion bus, or from its own pluggable connector. The on-board relays are powered at +5V (See Schematic).

Raspberry Pi current consumption: | 250 mA @ +5V (could be as high as 2A)
16-RELAYS Card current consumption: | 10 mA @ +5V (all relays OFF)
| 700 mA @ +5V (all relays ON)

The power connector which powers the 16-RELAYS card can supply up to 4A and is protected by a 3A resettable fuse. We recommend using a 5V regulated power supply rated at 3A or higher. The 16-RELAYS card can be stacked up to eight levels. A multi-stack configuration can be powered from any of the cards.

If your application requires multiple relays to be ON at the same time, we recommend using a power supply rated 4A or higher, with a split cable to power multiple cards.

### MECHANICAL SPECIFICATIONS

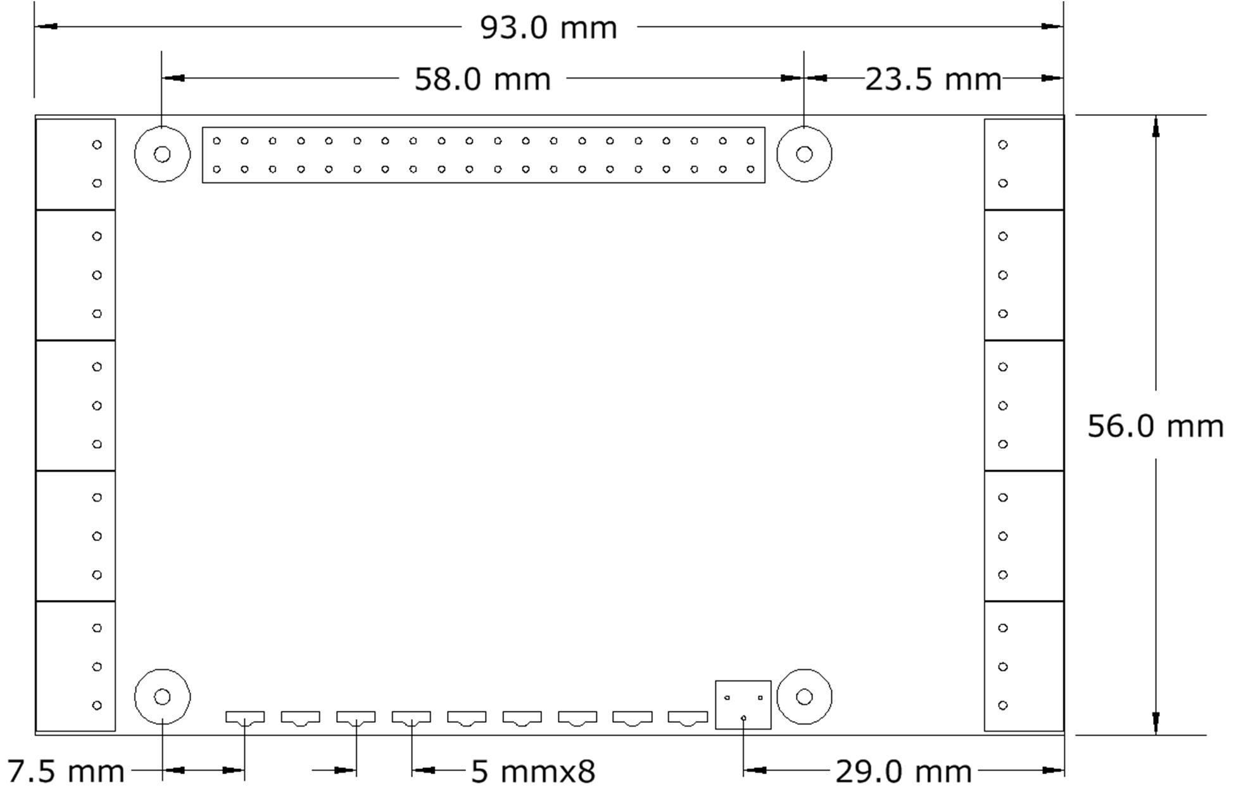
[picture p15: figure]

The card is compatible with any card manufactured by Sequent Microsystems and can be mounted in any order. You may also mix cards from other vendors, assuming they do not use the same I2C address. It can be installed in the 3d-printable modular enclosure available for download from our website.

### SOFTWARE SETUP

The 16-RELAYS board occupies the I2C addresses from 0x20 to 0x27.

1. Have your Raspberry Pi ready with the latest OS.
2. Enable I2C communication:

~$ sudo raspi-config

1. Change User Password | Change password for default user
2. Network Options | Configure network settings
3. Boot Options | Configure options for start-up
4. Localisation Options | Set up language and regional settings to match..
5. Interfacing Options | Configure connections to peripherals
6. Overclock | Configure overclocking for your Pi
7. Advanced Options | Configure advanced settings
8. Update | Update this tool to the latest version
9. About raspi-config | Information about this configuration
P1 | Camera | Enable/Disable connection to the Raspberry Pi Camera
P2 | SSH | Enable/Disable remote command line access to your Pi
P3 | VNC | Enable/Disable graphical remote access to your Pi using...
P4 | SPI | Enable/Disable automatic loading of SPI kernel module
P5 | I2C | Enable/Disable automatic loading of I2C kernel module
P6 | Serial | Enable/Disable shell and kernel messages to the serial port
P7 | 1-Wire | Enable/Disable one-wire interface
P8 | Remote GPIO Enable/Disable remote access to GPIO pins
3. Install the 16relind software from github.com:

~$ git clone https://github.com/SequentMicrosystems/16relind-rpi.git

4. ~$ cd /home/pi/16relind-rpi
5. ~/16relind-rpi$ sudo make install
6. ~ $ 16relind

The program will respond with a list of available commands.

Type "16relind -h" for online help.

After installing the software, you can update it to the latest version with the commands:

1. ~$ cd /home/pi/16relind-rpi
2. ~/16relind-rpi$ git pull
3. ~/16relind-rpi$ sudo make install

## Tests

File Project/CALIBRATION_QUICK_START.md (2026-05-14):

# Valve Calibration Quick Start

Per-valve calibration corrects for manufacturing variance between solenoid valves. Each valve gets its own `mL/pulse` factor stored in the DB and applied automatically at runtime.

The **recommended path is the in-app Calibration Wizard**. A CLI tool is available for headless use.

---

## ⚡ Option A — In-App Wizard (Recommended, ~10 min per valve)

### Step 1: Prepare (2 min)
1. Place an empty pre-tared beaker under the target cage outlet.
2. Verify the reservoir is full and pressurized.
3. If the system was just started, let it warm up for ~30 min.
4. Open **Settings → Priming** and prime the lines if they contain air.

### Step 2: Run the Wizard
1. Open **Settings → Calibration** and click **Run Calibration Wizard**.
2. Select the cage(s) to calibrate (cage names from the Cages tab are shown).
3. Follow the on-screen prompts — the wizard executes the pulse train automatically.

### Step 3: Measure & Save
1. When prompted, enter the measured volume (in mL) from your lab scale.
2. The wizard computes the new `mL/pulse` factor and saves it to the DB.

### Step 4: Verify
Run a small test schedule (e.g. 0.5 mL) and confirm the delivered volume is within ±5 %.

---

## ⚡ Option B — CLI Tool (Headless / advanced)

### Step 1: Prepare (same as Option A)

### Step 2: Run Calibration
```bash
cd ~/rodent-refreshment-regulator/Project
python tools/valve_calibration_tool.py --cage 15 --interactive
```

### Step 3: Measure & Save
```
# Tool executes 250 pulses (~8 min) then prompts:
Enter measured volume (mL): 18.750
# Tool calculates: 18.750 / 250 = 0.075 mL/pulse
Save this calibration to database? yes
```

### Step 4: Verify
Run a small test schedule (0.5 mL) and confirm output is within ±5 %.

---

## 📊 Expected Results

| Stage | Target (mL) | Actual Before (mL) | Actual After (mL) | Error |
|---|---|---|---|---|
| **Before Calibration** | 1.000 | 2.863 | - | **186% ❌** |
| **After Calibration** | 1.000 | - | 1.000 ± 0.050 | **5% ✅** |

---

## 🔧 Calibrate All Valves

**In-app**: The Calibration Wizard supports multi-cage selection — pick all cages at once and the wizard sequences them with confirmation prompts.

**CLI**:
```bash
for cage in 1 2 3 4 5 6 7 8 9 10 11 12 13 14 15; do
  python tools/valve_calibration_tool.py --cage "$cage" --interactive
done
```

---

## 🎯 Quality Check

**Good Calibration:**
```
Volume per pulse:       0.075000 mL/pulse
Estimated CV:           0.27%
Quality: EXCELLENT ✅
```

**Bad Calibration (needs redo):**
```
Volume per pulse:       0.082000 mL/pulse
Estimated CV:           8.5%
Quality: POOR ❌
```

**Fix:** Increase pulses to 300:
```bash
python tools/valve_calibration_tool.py --cage 15 --num-pulses 300 --interactive
```

---

## 💡 Pro Tips

1. **Use Lab Scale:** ±0.001g precision minimum
2. **Warm Up System:** 30 minutes before calibration
3. **Full Reservoir:** Pressure affects volume
4. **Measure Water as-is:** 1g ≈ 1mL (at room temp)
5. **Recalibrate:** Every 3 months or after valve replacement

---

## 🆘 Troubleshooting

### "Tool says cage not found"
```bash
# Check relay connections
ls /dev/i2c-*  # Should show /dev/i2c-1
```

### "Volume seems wrong"
```bash
# 1. Check scale is tared
# 2. Ensure no spills
# 3. Run calibration again (3x), average results
```

### "Still over-delivering after calibration"
```bash
# 1. Verify database has entry
sqlite3 rrr_database.db "SELECT * FROM valve_calibration WHERE cage_id=15;"

# 2. Restart application
# 3. Check logs for "Using per-valve calibration"
```

---

## 📚 Full Documentation

See `VALVE_CALIBRATION_GUIDE.md` for:
- Complete technical explanation
- Root cause analysis
- Best practices
- API reference
- Advanced troubleshooting

---

**Next Steps:**
1. ✅ Calibrate cage 15 NOW (your active test cage)
2. ✅ Run test schedule to verify accuracy
3. ✅ Calibrate all cages used in experiments
4. ⏰ Schedule quarterly recalibration (add to calendar)

**Time Investment:** ~10 min per valve × 15 valves = **2.5 hours for complete system**

**Benefit:** **99% accuracy** vs. current 186% error = **Worth it!**

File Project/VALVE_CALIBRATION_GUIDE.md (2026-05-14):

# Valve Calibration Guide - RRR System
## Per-Valve Empirical Calibration for Precision Water Delivery

> **User-facing entry point:** `Settings → Calibration → Run Calibration Wizard` (`ui/CalibrationWizard.py`). For a step-by-step walkthrough use [CALIBRATION_QUICK_START.md](CALIBRATION_QUICK_START.md). This document is the technical reference behind the wizard.

---

## Table of Contents
1. [Problem Summary](#problem-summary)
2. [Root Cause Analysis](#root-cause-analysis)
3. [Solution Overview](#solution-overview)
4. [Calibration Workflow](#calibration-workflow)
5. [Technical Implementation](#technical-implementation)
6. [Best Practices](#best-practices)
7. [Troubleshooting](#troubleshooting)

---

## Problem Summary

**Symptoms:**
- Target: 1.0 mL delivery
- Actual: 2.863 mL measured (186% over-delivery)
- System reported: 1.000 mL delivered ✓
- Sensor readings: ~0.004-0.005 mL per pulse (shown in logs)
- Calibration expected: 0.026 mL per pulse
- **Calculated actual:** ~0.075 mL per pulse (2.863 mL ÷ 38 pulses)

**Impact:**
- Animals receiving ~3x target water volume
- Experimental data compromised
- Potential health risks from over-hydration

---

## Root Cause Analysis

### Issue 1: Global Calibration ≠ Individual Valve Behavior

**Problem:**
The system used a single calibration value (0.026 mL/pulse from `pulse_calibration.py`) for ALL valves.

**Reality:**
Manufacturing tolerances in Parker Series 3 valves cause 10-30% variation between units.

**Your Valve's Behavior:**
- Hardcoded: 0.026 mL/pulse
- Actual: ~0.075 mL/pulse
- Error: **188% over-delivery**

### Issue 2: Sensor Integration Window Too Narrow

**Problem:**
The sensor measurement window **completely missed the bulk flow**:

**Original Flow (BROKEN):**
```
Time:     [----valve opens----|----valve closes----|----settling----|----measurement window----]
Flow:     [████████ BULK ████]  [██ tail ██]        [░ settling ░]   [measure: 0.005 mL]
Missed:   [~~~NOT MEASURED~~~]  [NOT MEASURED]      [NOT MEASURED]   [✓ measured]
```

**The system was:**
1. Suspending sensor reads BEFORE opening valve
2. Opening valve (bulk flow happens here: ~0.070 mL)
3. Closing valve
4. Resuming sensor reads
5. Measuring only tail/settling (~0.005 mL)
6. Reporting: "Pulse volume deviation: 82% diff" ← **System detected the problem but kept using wrong value!**

**Fixed Flow (NEW):**
```
Time:     [----valve opens----|----valve closes----|----settling----]
Flow:     [████████ BULK ████]  [██ tail ██]        [░ settling ░]
Measure:  [✓✓✓✓✓ CONTINUOUS MEASUREMENT ✓✓✓✓✓✓✓✓✓✓✓✓✓✓]
```

Now captures:
- Valve opening transient
- Bulk flow
- Valve closing transient
- Settling period
- **Total: Full delivery profile**

---

## Solution Overview

### Three-Tier Hybrid System

**Tier 1: Per-Valve Empirical Calibration (Primary)**
- Run 200-300 pulses per valve
- Gravimetric measurement (lab scale ±0.001g)
- Calculate: mL_per_pulse = total_volume / num_pulses
- Store in database per cage

**Tier 2: Real-Time Sensor Feedback (Validation)**
- Integrate full flow curve (not just tail)
- Compare measured vs. calibrated values
- Adaptive weighting based on deviation

**Tier 3: Drift Detection & Alerts**
- Track sensor vs. calibration over time
- Alert if deviation >20% sustained
- Recommend recalibration

---

## Calibration Workflow

### Prerequisites
- Lab scale with ±0.001g precision
- Empty collection beaker
- System warm-up: 30 minutes
- Full fluid reservoir

### Step-by-Step Process

#### 1. Prepare Equipment
```bash
# 1. Verify system is in solenoid + pulse mode
# 2. Check fluid reservoir is FULL
# 3. Place beaker under cage output
# 4. Tare scale with empty beaker
```

#### 2. Run Calibration Tool
```bash
cd /Users/zes/.cursor/worktrees/rodRefReg/P9fOC/Project
python tools/valve_calibration_tool.py --cage 15 --interactive
```

**Interactive Mode Prompts:**
```
VALVE CALIBRATION - Cage 15 (Relay 15)
======================================
Pulse width: 20ms
Number of pulses: 250

PRE-FLIGHT CHECKLIST:
  1. Verify fluid reservoir is FULL
  2. Place empty beaker under cage 15 output
  3. Tare your lab scale with empty beaker
  4. Ensure system has been running >30min (stable temp)

Press ENTER when ready to begin calibration...

Executing 250 pulses...
(This will take ~8.3 minutes)
  Progress: 50/250 (20.0%) - Elapsed: 95.3s
  Progress: 100/250 (40.0%) - Elapsed: 190.1s
  Progress: 150/250 (60.0%) - Elapsed: 285.8s
  Progress: 200/250 (80.0%) - Elapsed: 380.2s
  Progress: 250/250 (100.0%) - Elapsed: 475.6s
✓ Completed 250 pulses in 476.2s

MEASUREMENT:
  1. Remove beaker from under cage output
  2. Weigh beaker on lab scale
  3. For water: weight in grams ≈ volume in mL

Enter measured volume (mL): 18.750

======================================================================
CALIBRATION RESULTS
======================================================================
Total volume measured:  18.7500 mL
Number of pulses:       250
Volume per pulse:       0.075000 mL/pulse
Estimated CV:           0.27%

Quality: EXCELLENT

Save this calibration to database? (yes/no): yes
✓ Calibration saved to database (ID: 1)
✓ Calibration complete and saved!
  Cage 15: 0.075000 mL/pulse
```

#### 3. Verify Calibration
```bash
# Check database
sqlite3 rrr_database.db "SELECT * FROM valve_calibration WHERE cage_id=15;"
```

**Expected Output:**
```
calibration_id|cage_id|relay_id|pulse_width_ms|volume_per_pulse_ml|stddev_ml|coefficient_of_variation_pct|num_samples|calibration_date|calibrated_by|notes
1|15|15|20|0.075|0.000212|0.27|250|2025-11-04T14:30:15.123456|1|Empirical calibration: 250 pulses @ 20ms
```

#### 4. Test Delivery
Run a small test schedule (e.g., 0.5 mL) and verify with scale:
- Target: 0.5 mL
- Expected pulses: ~7 (0.5 / 0.075)
- Measured: 0.500 ± 0.010 mL ✓

---

## Technical Implementation

### Database Schema

**`valve_calibration` Table:**
```sql
CREATE TABLE valve_calibration (
    calibration_id INTEGER PRIMARY KEY AUTOINCREMENT,
    cage_id INTEGER NOT NULL UNIQUE,
    relay_id INTEGER NOT NULL,
    pulse_width_ms INTEGER NOT NULL,
    volume_per_pulse_ml REAL NOT NULL,      -- Main calibration value
    stddev_ml REAL,                          -- Standard deviation
    coefficient_of_variation_pct REAL,       -- CV% (should be <5%)
    num_samples INTEGER NOT NULL,            -- Number of pulses (200-300)
    calibration_date TEXT NOT NULL,
    calibrated_by INTEGER,                   -- Trainer ID
    notes TEXT
);
```

**`valve_calibration_history` Table:**
- Same schema as above
- Tracks ALL calibrations for drift analysis

### Code Flow

#### 1. Initialization (RelayWorker)
```python
# Pass database handler to strategy
self.strategy = StrategyFactory.create(
    'solenoid',
    solenoid_controller=solenoid,
    flow_sensor=flow_sensor,
    calibration_store=cal_store,
    settings=system_settings,
    database_handler=self.system_controller.database_handler,  # NEW
)
```

#### 2. Per-Pulse Delivery (SolenoidFlowStrategy)
```python
async def _execute_single_pulse(self, cage_id: int) -> float:
    # 1. Get per-valve calibration from database
    expected_vol_ml = await self._get_valve_calibration_value(cage_id)
    
    # 2. Clear sensor queue
    self._sensor.clear_queue()
    
    # 3. Execute pulse while collecting samples CONTINUOUSLY
    samples = []
    self._valves.open_cage(cage_id)
    while valve_open:
        sample = self._sensor.read_one()
        samples.append(sample)  # Capture DURING opening
        await asyncio.sleep(0.05)
    
    self._valves.close_cage(cage_id)
    while settling:
        sample = self._sensor.read_one()
        samples.append(sample)  # Capture DURING settling
        await asyncio.sleep(0.05)
    
    # 4. Integrate full flow curve
    delivered_ml = trapezoidal_integration(samples)
    
    # 5. Adaptive correction
    if sensor_reading_reasonable:
        weight = adaptive_weight(deviation_pct)
        final_volume = (sensor * weight) + (calibration * (1-weight))
    else:
        final_volume = expected_vol_ml  # Fallback to calibration
    
    return final_volume
```

#### 3. Database Lookup
```python
async def _get_valve_calibration_value(self, cage_id: int) -> float:
    # Try database first
    cal = self._db.get_valve_calibration(cage_id)
    if cal and cal['pulse_width_ms'] == self._pulse_width_ms:
        return cal['volume_per_pulse_ml']  # Per-valve value!
    
    # Fallback to global
    return self._empirical_pulse_volumes.get(self._pulse_width_ms, 0.026)
```

### Adaptive Correction Algorithm

**Goal:** Trust sensor when it's working, use calibration as fallback

```python
deviation_pct = abs(sensor_ml - calibration_ml) / calibration_ml * 100.0

if deviation_pct > 50.0:
    # Sensor clearly wrong (e.g., disconnected)
    use_value = calibration_ml
elif deviation_pct < 20.0:
    # Good agreement, trust sensor more
    weight_sensor = 0.7
    use_value = (sensor_ml * 0.7) + (calibration_ml * 0.3)
else:
    # Moderate disagreement, blend
    weight_sensor = 1.0 / (1.0 + deviation_pct / 100.0)
    use_value = (sensor_ml * weight_sensor) + (calibration_ml * (1 - weight_sensor))
```

---

## Best Practices

### When to Calibrate

**Must Calibrate:**
- ✅ New valve installation
- ✅ Valve replacement
- ✅ Pressure change in system
- ✅ Fluid type change (water → saline)
- ✅ After maintenance on manifold

**Should Calibrate:**
- ⚠️ Every 3 months (routine)
- ⚠️ If delivery accuracy >10% error for 3+ consecutive schedules
- ⚠️ After 10,000+ valve cycles (wear)

**Optional Calibrate:**
- 🔄 Seasonal (temperature affects valve timing)
- 🔄 After firmware updates

### Calibration Quality Metrics

| Coefficient of Variation (CV%) | Quality | Action |
|---|---|---|
| < 1% | EXCELLENT | ✅ Production ready |
| 1-3% | GOOD | ✅ Production ready |
| 3-5% | ACCEPTABLE | ⚠️ Monitor closely |
| > 5% | POOR | ❌ Re-calibrate with more pulses or check hardware |

### Sample Size Guidelines

| Valve Type | Recommended Pulses | Time @ 20ms pulse |
|---|---|---|
| Parker Series 3 | 250 | ~8 minutes |
| High-precision required | 300 | ~10 minutes |
| Quick check | 100 | ~3 minutes |

**Math:**
- Standard error = (scale_precision / √num_pulses)
- For ±0.001g scale and 250 pulses: SE = 0.001 / √250 = 0.000063 g ≈ 0.00006 mL
- CV% = (SE / mean) × 100%

### Per-Cage vs. Global Calibration

**Use Per-Cage Calibration (Recommended):**
- Different valves per cage
- High precision required (<5% error)
- Experimental research

**Use Global Calibration (Not Recommended):**
- All valves from same batch
- Moderate precision acceptable (10% error)
- Quick prototyping

---

## Troubleshooting

### Issue: CV > 5% (Poor Stability)

**Possible Causes:**
1. **Insufficient pulses** → Increase to 300
2. **Pressure instability** → Check reservoir level, pump operation
3. **Valve sticking** → Clean valve, check for debris
4. **Temperature drift** → Allow 30min warm-up
5. **Scale precision** → Use lab-grade scale (±0.001g minimum)

**Diagnostic Test:**
```bash
# Run calibration 3 times consecutively
python tools/valve_calibration_tool.py --cage 15 --num-pulses 100 --interactive
# Compare results - should be within 5%
```

### Issue: Sensor Measurement ≠ Calibration

**Symptoms:**
```
Adaptive correction: sensor=0.045mL, cal=0.075mL, using=0.060mL (dev=40%)
```

**Possible Causes:**
1. **Sensor partially blocked** → Check sensor for debris
2. **Air bubbles** → Prime system thoroughly
3. **EMI from valves** → Check grounding, shielding
4. **Sensor calibration drift** → Recalibrate sensor (see sensor manual)
5. **Pressure transient** → Adjust pulse settling time

**Action:**
- If deviation < 50%: System uses adaptive correction (OK)
- If deviation > 50%: System uses calibration (OK, but investigate)
- If sustained high deviation: Check sensor health

### Issue: System Still Using Old Global Calibration

**Check:**
```bash
# 1. Verify database entry exists
sqlite3 rrr_database.db "SELECT * FROM valve_calibration WHERE cage_id=15;"

# 2. Check logs for calibration lookup
grep "Using per-valve calibration" /path/to/logs/system.log

# 3. Restart application to reload database
```

### Issue: Calibration Tool Fails

**Error: "Solenoid controller not found"**
```bash
# Ensure relay hat is connected
ls /dev/i2c-*
# Should show /dev/i2c-1

# Test relay manually
python -c "import SM16relind; SM16relind.set(0, 1, 1)"
```

**Error: "Database locked"**
```bash
# Close any open connections
killall python3
# Retry calibration
```

---

## Migration Path (For Existing Systems)

### Scenario 1: Fresh System (No Calibration)

**Status:** Currently using hardcoded defaults (0.026 mL/pulse)

**Action:**
1. Calibrate all valves using tool
2. System automatically switches to per-valve calibration

### Scenario 2: Existing System with Global Calibration

**Status:** Using `pulse_calibration.json`

**Action:**
1. Calibrate critical valves (used in active experiments)
2. System uses per-valve where available, falls back to global
3. Gradually calibrate remaining valves

### Scenario 3: System with Incorrect Global Calibration

**Status:** Your situation - 0.026 mL hardcoded, actual ~0.075 mL

**Action:**
1. **IMMEDIATE:** Calibrate cage 15 (your test cage)
```bash
python tools/valve_calibration_tool.py --cage 15 --num-pulses 250 --interactive
```

2. **SHORT-TERM (this week):** Calibrate all active cages

3. **LONG-TERM:** Schedule quarterly recalibration

---

## API Reference

### Database Methods

```python
from models.database_handler import DatabaseHandler

db = DatabaseHandler('rrr_database.db')

# Save calibration
cal_id = db.save_valve_calibration(
    cage_id=15,
    relay_id=15,
    pulse_width_ms=20,
    volume_per_pulse_ml=0.075,
    stddev_ml=0.000212,
    cv_pct=0.27,
    num_samples=250,
    calibrated_by=1,  # trainer ID
    notes="Initial calibration"
)

# Load calibration
cal = db.get_valve_calibration(cage_id=15)
print(f"Calibrated volume: {cal['volume_per_pulse_ml']:.6f} mL/pulse")

# Get all calibrations
all_cals = db.get_all_valve_calibrations()
for cage_id, cal in all_cals.items():
    print(f"Cage {cage_id}: {cal['volume_per_pulse_ml']:.6f} mL/pulse")

# Get calibration history
history = db.get_valve_calibration_history(cage_id=15, limit=10)
for entry in history:
    print(f"{entry['calibration_date']}: {entry['volume_per_pulse_ml']:.6f} mL/pulse")
```

### Command-Line Tool

```bash
# Interactive mode (recommended)
python tools/valve_calibration_tool.py --cage 15 --interactive

# Automated mode (for scripting)
python tools/valve_calibration_tool.py \\
    --cage 15 \\
    --num-pulses 250 \\
    --pulse-width-ms 20 \\
    --measured-ml 18.750 \\
    --trainer-id 1

# Custom pulse count
python tools/valve_calibration_tool.py --cage 15 --num-pulses 300 --interactive

# Quick test (100 pulses)
python tools/valve_calibration_tool.py --cage 15 --num-pulses 100 --interactive
```

---

## Summary

**What Changed:**
1. ✅ **Database schema** for per-valve calibration storage
2. ✅ **Calibration tool** following colleague's proven 200-300 pulse method
3. ✅ **Fixed sensor integration** to capture full flow curve (not just tail)
4. ✅ **Adaptive correction** blending sensor + calibration intelligently
5. ✅ **Per-valve lookup** in delivery strategy
6. ✅ **Drift detection** via calibration history

**What to Do Next:**
1. **Calibrate your valve (cage 15):**
   ```bash
   python tools/valve_calibration_tool.py --cage 15 --interactive
   ```
   
2. **Run test schedule** to verify accuracy

3. **Calibrate remaining valves** in active use

4. **Schedule quarterly recalibration**

**Expected Results:**
- **Before:** 1.0 mL target → 2.863 mL actual (186% error)
- **After:** 1.0 mL target → 1.000 ± 0.05 mL actual (<5% error)

---

## References

- [Sensirion SLF3S-0600F Datasheet](https://sensirion.com/media/documents/C4F8D965/66F56F53/LQ_DS_SLF3S-0600F_Datasheet.pdf)
- [Parker Series 3 Valve Manual](https://www.parker.com)
- [User Rules: Database Interaction Guidelines](../user_rules)
- [Pulse Mode Implementation Documentation](./PULSE_MODE_COMPLETE_SUMMARY.md)

---

**Created:** 2025-11-04  
**Last Updated:** 2025-11-04  
**Version:** 1.0  
**Author:** RRR Development Team

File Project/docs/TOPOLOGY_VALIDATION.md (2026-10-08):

# Topology Validation — proving the independent rig against the manifold rig

RRR runs two valve topologies from one codebase ([HARDWARE_SETUP.md §7.2](HARDWARE_SETUP.md#72-why-the-master-valve-is-on-channel-16)):

| `valve_topology` | Fluid path | Per delivery |
|---|---|---|
| `shared_manifold` (default; the production rig) | one syringe → master valve (relay 16) → manifold → one valve per cage | master primed and held open across the pulse train |
| `independent` | one syringe → one valve → one spout, per animal | cage valve pulsed only; relay 16 never driven |

Before an animal goes on an independent rig, this document is how the lab shows it delivers water **as precisely as the manifold rig**. It pre-declares the criteria (nothing is decided after seeing the numbers), gives the bench recipe, and names the tools that grade the result. Criteria C1–C8 are beaker tests; only C9 involves an animal.

**Both rigs run the same tagged release** (v1.21.0 or later, which records the context of every delivery). The only difference between them is one setting, **Settings → Delivery → Valve Topology** (§3.1). Never put a `-beta` tag on a device for this: the updater ignores pre-releases and the device is stranded.

---

## 1. Principles

1. **Compare to what was fired, not to the nominal dose.** Water leaves a valve in whole pulses. The figure to hold a rig to is `pulses_fired × mL/pulse`; the distance between that and the dose is the planner's rounding, graded separately (C3). The ledger records both sides per delivery: the dose asked for (`volume_requested_ml`) with the rounding policy applied (`dose_rounding`), and the pulses fired with the mL/pulse they were fired at. A rig that fires the right pulses for the dose and delivers their calibrated volume has done its job.
2. **Freeze the calibration before the doses.** Calibrate a cage (C1), then run its dose sets against that calibration. Recalibrating between sets makes the sets incomparable; the app now records which calibration row each delivery used, so a mixed set is visible in the ledger.
3. **Characterise the hardware under nearest rounding, validate the production policy.** Run C1–C4 with **Settings → Delivery → Pulse Mode → "Round doses up"** *off*, so the shortfall you measure is physics, not policy. Run C5–C9 with the setting the animals will actually get (on the manifold rig with the needle, that is *on*; see [CALIBRATION_QUICK_START.md → Dose rounding policy](CALIBRATION_QUICK_START.md#dose-rounding-policy)).
4. **Weigh promptly.** The lab's animals drink immediately, so evaporation is not modelled; on the bench, weigh within a minute of the delivery. Record the raw balance readings, never a mental subtraction.
5. **n = 10 per cell**, three or more doses, as ISO 8655-6 does for pipettes. Below ten the tools list a cell but refuse to grade it.

### The manifold baseline (Parker 003-0257-900, 30 ms pulse / 1000 ms interval)

These are the bench figures the criteria are graded against. They come from the manifold rig's own beaker runs (see the calibration sheets); refresh them if the rig or the profile changes.

| Quantity | Value |
|---|---|
| mL per pulse, `q` | 34.164 µL without the upstream needle; **32.936 µL with the 16 G needle the lab keeps** |
| Pulse calibration CV (three 250-pulse runs) | 1.0 % |
| Dose CV, 0.3–1.0 mL, n = 10 | 3.1–3.9 % with the needle (4.5–5.5 % without it) |
| Per-dose shortfall vs pulses × q (needle rig) | 13–19 µL at 0.3–0.7 mL, about half a pulse; at 1.0 mL it varied between days (about 4 µL one day, 26–59 µL another) |
| Lab tolerance | **5 % maximum** on any dose (the mice take 0.6, 0.7 and 1.0 mL per day) |

---

## 2. Acceptance criteria

`q` is the cage's own mL/pulse from C1; `q/2` is half a pulse (≈ 16 µL on the needle rig).

| # | Criterion | Test | Pass (independent rig) | Graded by |
|---|---|---|---|---|
| **C1** | Pulse calibration | Every cage that will carry an animal: 250 pulses × 3 runs at 30 ms / 1000 ms through the wizard | CV of the three run means ≤ 1.5 % (manifold 1.0 %); first→last run drift ≤ 3 %; q ≤ 40 µL | Wizard figures, recorded by hand (§3.2) |
| **C2** | Precision | 0.3 / 0.6 / 0.7 / 1.0 mL, n = 10 each, via a real instant schedule, each weighed | CV ≤ 5.0 % **and** not significantly less precise than the manifold at the same dose: pooled within-cage variance ratio within the one-sided F bound at a family-wise 5 % (about 2.2 × the manifold's SD for four doses at ten rows a side) | `topology_compare.py` |
| **C3** | Planner parity | Every weighed instant delivery, from the ledger | `pulses_fired` equals the count the recorded rounding policy gives for the dose asked for, and that policy is the one the set requires (nearest for C2–C4). A `mismatch` is a code regression, never a hardware finding | `topology_compare.py --policy nearest` (`gravimetric_check.py list` shows it per row) |
| **C4** | Trueness / shortfall | Per dose, under nearest rounding | \|mean weighed − pulses × q\| ≤ q/2. The manifold rig's own shortfall is reported beside it as the baseline, not graded: with neither needle nor manifold, ≈ 0 is the expected and informative result for the independent rig | `topology_compare.py` |
| **C5** | Daily total | Simulated 0.6 mL and 1.0 mL mouse-days in the staggered chunks the schedule uses, ≥ 3 consecutive days, production rounding policy | Each day's weighed total within ± 5 % of the prescribed day | `gravimetric_check.py daily` + the day's weighing (§3.5) |
| **C6** | Start-up after idle | First dose after ≥ 12 h idle and after a 48 h weekend | Within C2/C4; \|first dose − mean of the next nine\| ≤ q/2 (a primed syringe line is reported to hold ~3 days; this measures it) | `gravimetric_check.py` rows, compared by hand |
| **C7** | Drift over days | 0.6 mL × 10 on days 1, 3 and 7, same calibration | Each day's mean within ± 3 % of day 1 | `topology_compare.py --since D --until D`, one day at a time |
| **C8** | Syringe fill level (independent-specific) | 0.6 mL × 10 with the syringe full, half full, and ≤ 2 mL | Mean shift between fill levels ≤ q/2. A larger shift means a fill-level term is needed before animals go on (none exists in the delivery path today) | `topology_compare.py` on one readings file per fill level (`gravimetric_check.py --csv`) |
| **C9** | Operational (the only animal criterion) | Every cage that will carry an animal passes C1 and the 0.6 mL × 10 set; the full dose grid and C6–C8 on ≥ 3 representative cages; then one animal per cage on ≥ 3 cages for ≥ 14 days | Daily weights and per-animal delivered totals within ± 5 % of the prescribed day; partial / failed / `sensor_failure` row rate no higher than the manifold rig's | Animal records + ledger |

**Equivalence.** "As precise as the manifold rig" means, at each dose, that the independent rig's repeatability is not significantly worse than the manifold's: s²_independent / s²_manifold ≤ F(1 − 0.05/k; df_independent, df_manifold), a one-sided F test at a family-wise 5 % over the k doses compared (Bonferroni). s² is the pooled within-cage variance of each row's deviation from its own plan (weighed − pulses × q), so neither cages whose mL/pulse differ (and therefore plan different volumes for the same dose) nor a cage recalibrated between rows inflate it. C2's CV uses the same SD. A rig exactly as precise as the manifold passes 95 % of the time; at ten rows a side the bound is 1.78 × the manifold's SD for one dose and 2.24 × for four. C2's absolute 5 % CV cap applies on top. `topology_compare.py` grades it once each rig has a cage with ten weighed rows at the dose, and reports the difference between the rigs' mean weighed volumes and between their shortfalls for information. Trueness is judged per rig, never rig against rig: each against its own pulses × q (C4) and against the prescribed day (C5). The rigs' means differ by design: their mL/pulse differ (0.6 mL is 18 pulses on both, but 0.593 mL of plan on one and 0.615 mL on the other), and the manifold's needle keeps about half a pulse per dose.

> **Revised 2026-09-29, before any validation data was collected.** The first version also required the two rigs' mean weighed doses to agree within 2.5 % of the dose. That contradicted principle 1 and this document's own expected result: the manifold's shortfall of about half a pulse is 2.7–5.5 % of a 0.3–0.6 mL dose, and the pulse-size difference alone is 3.7 % at 0.6 mL, so an independent rig behaving exactly as expected would have failed. The precision limit and every other threshold are unchanged.
>
> **Revised again 2026-09-29, still before any data.** The precision rule was SD_independent ≤ SD_manifold × 1.371, CLSI EP15-A3's upper verification limit. That limit verifies a rig against a *claimed* SD taken as known; here the manifold's SD is itself a ten-row estimate, so a rig exactly as precise as the manifold would have failed about 18 % of doses and 55 % of four-dose runs. The rule is now the two-sample F test above, at a family-wise 5 %, on pooled within-cage variances. The same day, before any data, the variances were defined about each row's own plan, so a change of plan within a cage is not counted as noise; with the calibration frozen as principle 2 requires, the figures are unchanged.

**Exit.** Every criterion passes on every animal-carrying channel across the three-day window, and the 14-day observation shows no weight excursions. After that both rigs simply keep running the same releases; the topology setting is a permanent configuration, not a flag to remove.

---

## 3. Bench recipe

### 3.1 Set up the independent rig

1. Build and wire per [HARDWARE_SETUP.md](HARDWARE_SETUP.md): one relay per valve, relay 16 **unwired** (it stays reserved on this release).
2. Install the same release as the manifold rig. The version is in the main window's title bar (and in `~/rrr/current/Project/version.py`).
3. Set the topology: log in, open **Settings → Delivery → Valve Topology**, click **Independent (one syringe and one valve per animal)** and confirm with **Restart RRR**. The change is refused while a schedule, a priming session or a calibration runs. RRR records the change with your user name in its database (the `logs` table, action `valve_topology`) and restarts; log in again, and the priming tab shows no master valve controls. With the app closed, `~/rrr/shared/venv/bin/python3 tools/set_valve_topology.py independent --yes` (run from `~/rrr/current/Project`) does the same without the `logs` record; it refuses to write while it can see the app running.
4. Prime each line from **Settings → Priming** (on the independent rig there is no master step: select the cage, **Open Selected**, **Close Selected**). Check the lines every day; a primed syringe line has been seen to hold about three days.
5. Fill each syringe to a known level and note it (C8 uses the level).

### 3.2 C1 — calibrate and freeze

For every cage that will carry an animal, in **Settings → Calibration** click **Calibrate** on the cage's row (**Recalibrate** once it has one): 250 pulses, **30 ms pulse width, 1000 ms interval**, weigh, **Save & Finish**. Repeat three times and write down the three mL/pulse figures per cage:

| cage | run 1 | run 2 | run 3 | CV of the three (%) | drift run 1→3 (%) | q saved (µL) |
|---|---|---|---|---|---|---|

CV ≤ 1.5 %, drift ≤ 3 %, q ≤ 40 µL. The **last** saved run is the calibration in force; do not recalibrate that cage again until its dose sets are done. In solenoid pulse mode (the default), Run refuses a schedule that waters a cage with no usable calibration measured under this device's valve topology (*Valve calibration needed*), so a cage's C2–C4 schedules cannot start until its C1 run is saved. On a rig switched from the manifold, the old calibrations show **Stale** in **Settings → Calibration** (measured under the other valve topology; one saved before v1.21.0 counts as shared manifold) and count as none.

### 3.3 C2–C4 — weighed doses

With **"Round doses up" off**:

1. Put a tared beaker under the cage.
2. Create an **instant** schedule (schedule wizard, step 1: *Instant*) with one animal on that cage and the dose (0.3, 0.6, 0.7 or 1.0 mL), run it, weigh promptly. Ten times per dose per cage. The app writes one `dispensing_history` row per delivery.
3. On the device, list the deliveries and record each weighing against its row id (the database is opened read-only, so this is safe while the app runs):
   ```bash
   cd ~/rrr/current/Project
   ~/rrr/shared/venv/bin/python3 tools/gravimetric_check.py list --last 20
   ~/rrr/shared/venv/bin/python3 tools/gravimetric_check.py weigh 1234 --gross 12.7413 --tare 12.1435 --temp-c 22
   ~/rrr/shared/venv/bin/python3 tools/gravimetric_check.py weigh 1235 --net 0.5988            # balance tared
   ```
   `list` shows, per row, the topology, the dose asked for and the rounding policy, the pulses fired, mL/pulse, the plan (pulses × mL/pulse), the planner verdict, the calibration row and, once weighed, the measured volume and the shortfall. The verdict is `ok` when the pulse count is what the recorded policy gives for the dose and `mismatch` when it is not; a staggered chunk shows `carry` and a delivery that did not complete shows nothing. `weigh` keeps the raw gross and tare, the water temperature and the density it used, and a snapshot of the delivery row in `~/rrr/shared/data/gravimetric_checks.csv`. A second reading for the same row is refused unless you pass `--replace`.
4. Do the same doses on the manifold rig (same day where possible). Its rows carry `shared_manifold` and are the baseline side.

### 3.4 Grade

Copy both CSVs to a laptop and run the comparison (Python 3, no dependencies):

```bash
scp pi-manifold:~/rrr/shared/data/gravimetric_checks.csv manifold.csv
scp pi-independent:~/rrr/shared/data/gravimetric_checks.csv independent.csv
python3 Project/tools/topology_compare.py manifold.csv independent.csv --policy nearest --json report.json
```

The report groups completed instant deliveries by topology, cage and the dose asked for. Each cell shows n, mean, SD, CV, q, the plan, the shortfall, the bias against the dose and the planner verdicts, with C2 / C3 / C4 marks; the manifold's cells show its figures as the baseline (`ref`) and are graded on C3 only. Per dose it then compares the rigs' pooled within-cage SDs (ratio and F bound), with the mean and shortfall differences for information. The planner column shows the verdicts and, in brackets, the rounding policy the rows were recorded with. Rows that did not complete, staggered chunks and rows without a recorded dose are counted and left out.

Exit status 0 means every graded criterion passed. 1 means a criterion failed, or the run is INCOMPLETE: a dose that either rig ran has no cage with ten gradable readings on the other, or the manifold file contributed no gradable rows at all. 2 means an input file could not be used. A report with nothing graded is not a pass. Grading one rig on its own (C7, C8) needs `--reference none`; without it, a run with no manifold rows, or with no rows from the independent rig, is INCOMPLETE rather than a pass. Keep `report.json` with the run.

### 3.5 C5–C8 — days, idle, drift, fill level

Switch **"Round doses up"** to the production setting first.

- **C5** — schedule a normal staggered day (the same chunking the animals get) at 0.6 mL and at 1.0 mL, three consecutive days, weighing the day's total per cage. The ledger side comes from the tool (the device has no `sqlite3` command):
  ```bash
  ~/rrr/shared/venv/bin/python3 tools/gravimetric_check.py daily --since 2026-10-05
  ```
  One line per day and cage: deliveries completed / partial / failed / other, and `dispensed_mL`, the sum of what the hardware reports it dispensed. Compare it with the prescribed day and with the day's weighing.
- **C6** — leave the rig idle ≥ 12 h, then a 48 h weekend; the first delivery after each idle is weighed with the next nine. Find the rows with a date-time bound, e.g. `gravimetric_check.py list --since 2026-10-06T08:00`.
- **C7** — the 0.6 mL × 10 set again on days 3 and 7 without recalibrating. Grade one day at a time out of the same readings file, and compare each day's mean with day 1 (± 3 %):
  ```bash
  python3 Project/tools/topology_compare.py independent.csv --reference none --since 2026-10-07 --until 2026-10-07
  ```
  Grading the whole file at once would pool the days and hide a drift.
- **C8** — the 0.6 mL × 10 set with the syringe full, half full and near empty, the same day. Weigh each fill level into its own readings file (`--csv` goes before the command, for `list` and `weigh` alike), grade each file, and compare the means (≤ q/2):
  ```bash
  ~/rrr/shared/venv/bin/python3 tools/gravimetric_check.py --csv ~/rrr/shared/data/c8_full.csv weigh 1301 --net 0.6012
  ~/rrr/shared/venv/bin/python3 tools/topology_compare.py ~/rrr/shared/data/c8_full.csv --reference none
  ```

### 3.6 C9 — animals

Only after C1–C8 pass on the cages concerned, and per the lab's welfare protocol: one animal per cage, daily weights, per-animal delivered totals from the ledger, and the row-status rate, all from one command on each rig:

```bash
~/rrr/shared/venv/bin/python3 tools/gravimetric_check.py daily --since 2026-10-15
```

---
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

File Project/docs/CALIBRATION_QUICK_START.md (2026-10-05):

# Valve Calibration Quick Start

Per-valve calibration corrects for manufacturing variance between solenoid valves. Each valve gets its own `mL/pulse` factor stored in the DB and applied automatically at runtime.

Since v1.16.0 a calibration also stores the **pulse timing profile** it was measured at — the pulse width and the valve-closed rest between pulses — and deliveries replay that same profile. Calibrate at the timing you intend to run; see [Pulse timing profile](#pulse-timing-profile) below.

Calibration runs in the in-app **Calibration Wizard**, one cage at a time. The standalone command-line tool that earlier versions of this guide described was removed in v1.21.0: it could not start.

---

## Calibrate a valve (~10 min per valve)

### Step 1: Prepare (2 min)
1. Place an empty pre-tared beaker under the target cage outlet.
2. Verify the cage's water supply: the reservoir full on a shared-manifold rig; on an independent rig, the cage's own syringe filled to its normal running level (the wizard's pre-flight checklist asks for the one your rig uses).
3. If the system was just started, let it warm up for ~30 min.
4. Open **Settings → Priming** and prime the lines if they contain air.

### Step 2: Run the Wizard
1. Open **Settings → Calibration**. The table has one row per cage in the device's cage map, with the names set in the Cages tab. Click **Calibrate** on the cage's row (**Recalibrate** if it already has one); the wizard opens for that cage.
2. Work through the **Pre-Flight Checklist**, then set the **Calibration Parameters**: the number of pulses, the **pulse width**, and the **inter-pulse interval**. The page shows the estimated run time and flags a hot duty cycle.
3. Click **Next**: the wizard fires the pulse train automatically. Progress updates live, and closing the wizard stops the run.

### Step 3: Measure & Save
1. Weigh the beaker and enter the **Measured Volume** in mL (1 g of water ≈ 1 mL).
2. The wizard shows the volume per pulse, the estimated CV and a quality rating. **Save & Finish** stores it; the cage's row in the table then shows **[OK]**, the mL/pulse and the date.

### Step 4: Verify
Run a small test schedule (e.g. 0.5 mL) and confirm the delivered volume is within ±5 %.

---
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

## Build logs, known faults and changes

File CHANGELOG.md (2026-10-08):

# Changelog

Curated, operator-facing summary of each **published** RRR release (a
release = a git tag `v<x.y.z>` with a `.rrrupdate` bundle devices can
install via the in-app Updates tab), newest first. Most releases get one
line. A release that asks something of the operator starts with a
**Before you update** list. A version number that was set on `main` but
never tagged is folded into the next release's entry.

The release workflow publishes the tagged version's entry from this file,
verbatim, as the GitHub Release notes, and the in-app Updates tab shows
them. Versioning follows SemVer for RRR — see
[Project/docs/MAINTENANCE.md §2](Project/docs/MAINTENANCE.md#2-picking-the-version-number--semver-for-rrr).
Test-only / doc-only / tooling-only changes do not get a release and are
not listed here.

---

## 1.21.0 — valve topology, calibration gate, relay-failure reporting

This release also carries 1.18.1, 1.19.0 and 1.20.0, which were numbered
on `main` but never released.

**Before you update**

- **Calibrate every cage your schedules use.** In solenoid pulse mode (the
  default), Run refuses a schedule that waters a cage with no usable
  calibration measured under this device's valve topology (**Valve
  calibration needed**), and the dialog names those cages. Until now such a
  cage was dosed at a guessed ~0.026 mL per pulse, about 30 % too much
  water on the production valve. Before updating, open Settings >
  Calibration and calibrate every **Not Calibrated** row a schedule uses.
  After updating, look again before the next Run: this release also marks
  a calibration it cannot use as **Invalid**, and on a two-HAT device it
  lists cages 16–31 for the first time. Those cages could not be
  calibrated before, so allow about 10 minutes for each one a schedule
  uses.
- **A shared-manifold rig needs no other change.** Valve Topology defaults
  to *Shared manifold (master valve)*, calibrations made before this
  release count as shared-manifold ones, and a clean delivery drives the
  relays exactly as before.
- **Check the Slack token.** An older Settings bug blanked the stored Slack
  token whenever any setting changed. This release stops that, but it
  cannot bring back a token that is already gone. If notifications stopped,
  enter the token again in Settings > General > Slack Integration. It takes
  effect without a restart.

**What changes on the device**

- **Add (safety):** Run refuses a schedule while any cage it waters has
  - no calibration;
  - a missing, zero or invalid volume per pulse or pulse width;
  - a calibration measured under the other valve topology;
  - or is not a cage on this device (dialog **Cage not on this device**:
    edit the schedule).

  The dialog lists each cage and why. Calibrate those cages in Settings >
  Calibration, then press Run again. This applies in solenoid pulse mode
  (the default).
- **Fix (safety):** a relay command that does not reach its HAT is
  reported, and only water from a valve that actually opened is counted.
  - A delivery stops at the first valve command that did not switch, or
    at a pulse that failed for any other reason (`[VALVE ERROR] cage N:
    …; delivery stopped after …` in the Terminal tab). Only pulses whose
    valve opened are credited, and the retry asks only for the rest. The
    same line reports a dose refused or cut short by the pulse or time
    limit.
  - A close that does not reach its relay is retried twice at once, then
    after 20, 50 and 100 ms. A pulse whose close got through late is
    credited with the time its valve stayed open, at the valve's steady
    flow.
  - `[VALVE CRITICAL] … OPEN` has two wordings: *the valve may still be
    OPEN* for a valve seen to open whose close did not get through, and
    *the … valve's relay is not answering, so the valve cannot be confirmed
    closed; it may be OPEN* for a valve whose relay has not answered since
    the run started. A dead HAT therefore alarms. If a later close gets
    through, `[VALVE OK] … closed after all` clears the alarm.
  - Pump relays that do not switch off are retried once, then
    `[VALVE CRITICAL] relay unit N: …` says they may still be ON.
  - When the relays cannot be confirmed off, CLOSE ALL RELAYS shows
    **Emergency Stop Failed** and Stop shows **Relays Not Confirmed Off**.
    Both say to disconnect the valve power supply.
  - CLOSE ALL RELAYS (Settings > Priming) now also stops a running
    schedule. Before, the schedule carried on and opened its valves again
    at its next pulse. The stopped schedule does not resume: animals it
    had not finished watering get no more water from it, and Run starts
    it over (a staggered schedule gives every animal its whole dose
    again; an instant schedule skips the times that have passed).
  - CLOSE ALL RELAYS frees the hardware lock only when every relay is
    confirmed off and nothing is still running. After **Emergency Stop
    Failed** the hardware stays locked (Run and calibration unavailable)
    until a later press is confirmed or RRR is restarted.
  - The calibration wizard stops at a pulse whose valve did not open or
    close. Do not save a measurement from that run.
  - Esc in the calibration wizard stops the pulse run, as the window's X
    does. Before, Esc closed the window and the run carried on to its
    last pulse. A run that cannot be stopped (a relay command that does
    not return) keeps the hardware locked and shows **Calibration Did Not
    Stop**.
  - Priming keeps its session and the hardware lock while a cage valve
    may still be open after Close Master, until that valve is confirmed
    closed. While such a valve may be open, a failed Open Master does not
    free them either.
- **Fix (safety):** with the first HAT missing, relay commands are no
  longer shifted onto the next HAT, where they drove another animal's
  valve.
- **Fix (safety):** after Change Relay Hats, Priming (CLOSE ALL RELAYS
  included) uses the new HAT count and lists its cages. Before, it kept
  the relay handler it first built until RRR was restarted, so CLOSE ALL
  RELAYS did not switch a HAT added since and still reported every relay
  closed. Restoring a settings backup no longer changes the relay layout
  (the number of HATs, the master relay and the cage relays): change the
  number with Change Relay Hats.
- **Fix (safety):** starting RRR again while it is open (another click on
  its icon, for example) no longer opens a second RRR beside it, driving
  the same relays: the running RRR is asked to show its window instead
  (the desktop may only highlight it in the taskbar). Before, RRR stopped
  noticing such a start shortly after it opened. Such a start does not
  count as a failed one, so it cannot set off the automatic rollback to
  the previous version.
- **Add:** a **Valve Topology** choice in Settings > Delivery > Solenoid
  Mode Settings.
  - *Shared manifold (master valve)*: the production rig, where relay 16
    opens a master valve around every delivery.
  - *Independent (one syringe and one valve per animal)*: relay 16 stays
    reserved, is never driven, and should be left unwired.

  The choice is greyed out while a schedule, priming or calibration runs.
  Changing it asks **Restart RRR** or **Cancel**; confirming saves the
  change and restarts RRR, so priming, calibration and schedules all use
  the new topology. If RRR cannot restart itself it says so, and Priming
  waits until RRR is reopened. RRR records who changed it, and when, in
  its database's log. Every start prints `[TOPOLOGY] Valve topology: …`.
- **Add:** each calibration records the topology it was measured under.
  Settings > Calibration marks a calibration measured under the other
  valve topology **Stale**, and Run refuses it. After switching the
  topology, recalibrate every cage.
- **Add:** Settings > Calibration marks a stored calibration whose volume
  per pulse or pulse width is missing, zero or invalid **Invalid** (red),
  and highlights its Recalibrate button; Run refuses it too. The table's
  statuses are now [OK], Stale, Invalid and Not Calibrated. **Calibrate
  All Uncalibrated** also runs the Stale and Invalid rows, and the CSV
  report marks Invalid rows `Invalid`. A missing CV shows as a dash
  instead of breaking the table.
- **Change:** on an independent rig, Priming hides the master controls,
  and opening a cage valve primes that animal's line. The Cages tab, the
  schedule wizard and Help describe relay 16 as reserved and unused. The
  Priming banner and the calibration checklist name the animal's syringe
  instead of the reservoir.
- **Add:** *Round doses up to the next whole pulse* in Settings >
  Delivery > Pulse Mode, off by default. With it on, a dose lands at most
  one pulse over its target instead of within half a pulse either side
  (1.19.0).
- **Fix:** a staggered window no longer fires one extra pulse from a
  rounding leftover (1.18.1).
- **Fix:** an instant delivery retried after a partial delivery sends
  only the rest. Before, it fired the whole dose again: 28 pulses for one
  0.6 mL dose.
- **Fix (two-HAT devices):** cage 16 can be scheduled (the wizard refused
  it as the master relay). Settings > Calibration, Calibrate All
  Uncalibrated, the CSV export and the wizard cover all 31 cages and drive
  each cage's real relay. Calibrate All Uncalibrated runs the whole batch
  instead of stopping after the first cage. The Calibration table
  refreshes after Change Relay Hats.
- **Fix:** the Hardware Mode choice is greyed out and refused while
  anything drives the hardware. Restoring a settings backup no longer
  changes the hardware mode or the valve topology.
- **Fix:** an unknown hardware mode is refused instead of running the
  pump strategy.
- **Fix:** a Slack token saved in Settings is kept and used at once.
  Auto-save no longer blanks it, and no longer fails for the rest of the
  session after a token is typed.
- **Fix (installer):** `install.sh --dry-run` runs to the end; a warning
  printed before its first section used to stop it. It also no longer
  leaves an empty `vendor/` folder in the checkout. The install's final
  check scans for the relay HAT (it skipped the scan for a normal user)
  and warns when the HAT is jumpered to a stack level other than 0, which
  RRR cannot use. `scripts/runtime/diagnose.sh` finds the installed Python
  environment and lists the relay HATs with their stack levels.
- **Change:** the Updates tab shows a release's notes formatted (headings,
  bold, lists), from the top and in the tab's full height, instead of as
  raw Markdown in a small box. The notes are the release's entry in this
  file.
- **Change:** each delivery record (`dispensing_history`) also stores the
  dose asked for, the rounding policy, the schedule mode, the valve
  topology, the calibration used, the pulse timing, the duration and the
  app version. The new columns are added automatically at the first start;
  older rows leave them empty.

**If something goes wrong**

- A HAT that was not found when RRR started stays missing until RRR is
  restarted. Fix the HAT or its I²C cable, then close and reopen RRR.
- **Emergency Stop Failed**, **Relays Not Confirmed Off** or `[VALVE
  CRITICAL]`: disconnect the valve power supply first, then check the
  relay HAT and its I²C connection.
- Rolling back on an independent rig: set Valve Topology back to *Shared
  manifold* before **Revert to previous version**. Releases before 1.21.0
  ignore the setting and drive relay 16 on every delivery.

**Developer notes**

- The release workflow publishes this file's entry for the tagged version
  as the GitHub Release notes, which the Updates tab shows. The test suite
  fails while `Project/version.py` names a version with no entry.
- `utils/topology.py` is the single decision point: `build_solenoid_controller`,
  `cage_map_from`, `calibration_is_stale`, `reserved_relay_reason`.
  `IndependentSolenoidController` has `has_master = False` and makes no
  relay writes for master operations. Master and cage relay ids below 1 are
  refused. (The `valve_topology` setting, `build_solenoid_controller` and
  `IndependentSolenoidController` were 1.20.0; the other helpers and the
  Settings control came with 1.21.0.)
- `utils/calibration_gate.py` (Qt-free) holds the Run gate, called from
  `RunStopSection._passes_calibration_gate`. The strategy's ~0.026 mL/pulse
  fallback and its use of stale rows stay only as a defence in depth.
- `RelayHandler.set_relays` / `set_all_relays` return False when a relay
  did not switch, and HATs are held one slot per stack. The pulse loop
  raises `ValveCommandError`. `FakeRelayHandler` reports a lost write as
  False. `test_topology_trace.py` pins the relay-write trace of both
  topologies.
- On a machine without the vendor relay library (a dev Mac), no HAT
  initialises, so schedule runs there now fail their deliveries instead of
  reporting success.
- Pump mode credits the triggers that fired, at pump volume ÷ calibration
  factor. This also changes a successful pump run's credit when the factor
  is not 1.0.
- `StrategyFactory.create` accepts only `solenoid` and `pump` and raises on
  anything else; `RelayWorker` resolves a missing mode to `solenoid`.
- `main.py` no longer builds a second, hidden `SettingsTab`, so
  `gui.settings_tab` is the visible one.
- `valve_calibration` and `valve_calibration_history` gain `topology`.
  `dispensing_history` gains `topology`, `calibration_id`,
  `pulse_width_ms`, `inter_pulse_interval_ms`, `duration_s`, `app_version`,
  `volume_requested_ml`, `dose_rounding` and `delivery_mode`. All are
  nullable and added by the PRAGMA-guarded migrations.
- Bench tools:
  - `tools/set_valve_topology.py`: CLI, run with the app closed; it also
    detects an app started from the desktop icon.
  - `tools/gravimetric_check.py` and `tools/topology_compare.py`: grade
    against `volume_requested_ml`.
  - The criteria are in `Project/docs/TOPOLOGY_VALIDATION.md`.
- Removed: `tools/valve_calibration_tool.py` (it could not start),
  `PulseCalibrator`, and the unused `gpio/mock_gpio_handler.py`.
- CI also runs the unit suite on Debian Bookworm with Python 3.11.
- `utils.updater.restart_app` relaunches through `~/.local/bin/rrr` only
  after the running process has exited (it gives up waiting after 60 s).
  The single-instance lock is keyed by version, so a restart that keeps
  the version, such as a valve topology change, would otherwise hand over
  to the old instance and exit.
- `scripts/install/test_install.sh` recognises a dry run that reached its
  end; it looked for a message the installer stopped printing in May 2026,
  so it failed every run. It checks that the dry run leaves the release
  tree, the venv, `vendor/`, `dist/` and the udev rule as it found them, so
  it also passes on a Pi where RRR is installed.

## 1.18.0 — whole-pulse doses

- **1.18.0** — Change: a staggered window fires whole pulses against its
  running shortfall (asked minus delivered). A chunk no longer rounds up to
  a whole pulse each time, which ends the measured over-delivery on
  staggered doses; a slot whose shortfall is under half a pulse is skipped
  and a later slot picks it up. An instant dose also rounds to the nearest
  whole pulse instead of up (a 0.6 mL dose at 0.1415 mL per pulse: 4
  pulses, 0.57 mL, where 1.17.0 fired 5, 0.71 mL).

## 1.17.0 — honest delivery accounting

- **1.17.0** — Change: the ledger records what actually left the valve
  (`volume_actual_ml`, `pulses_fired`, `volume_per_pulse_ml`, added
  automatically), and a delivery cut short is credited and logged as
  `partial` instead of zero. A retry asks only for the outstanding dose
  instead of +5 % per failure. Completion is judged within half a pulse
  instead of 0.01 mL.

## 1.16.x — calibration timing profile

- **1.16.1** — Fix: the calibration wizard accepts 10–1000 pulses (it
  accepted only 100–500).
- **1.16.0** — Feature: a calibration stores the rest between pulses,
  set in the wizard (**Inter-Pulse Interval**). Deliveries replay the
  pulse width and rest each cage was calibrated at; older calibrations
  keep the legacy 100 ms rest. A delivery whose estimated duration would
  exceed `max_pulse_delivery_time_s` (fixed at 120 s) is refused before
  any water moves, with the reason in the Terminal tab; before, the limit
  cut the dose off mid-way and the retry sent the whole dose again.
  Shorten the rest or split the dose. The calibration
  wizard runs its pulses off the GUI thread: the window no longer
  freezes, the progress bar is live, X cancels a run mid-way, and the
  master valve is closed on every exit (a mid-run error used to leave it
  open). (Tagged first as the pre-release 1.16.0-beta.)

## 1.15.x — hardware operation lock

- **1.15.1** — Change: controls locked by another hardware operation are
  greyed out.
- **1.15.0** — Feature (safety): schedule runs, priming and calibration
  share one hardware lock, and each refuses to start while another holds
  it (a "Hardware busy" message says which). CLOSE ALL RELAYS in Settings
  → Priming clears the lock.

## 1.13.0 – 1.14.2 — instant schedules

- **1.14.2** — Fix: pressing Run on an instant schedule (or dropping one
  into the run area) failed in 1.14.1 with a missing-method error; the
  method, removed by mistake in 1.14.1, is restored.
- **1.14.1** — Change: removed dead instant-delivery and legacy
  controller code.
- **1.14.0** — Change: instant deliveries run through the same delivery
  path as staggered ones. On solenoid hardware an instant dose now uses
  the cage's valve calibration and pulse width (and the flow sensor, when
  one is connected); before, it went through the legacy pump path (a
  generic trigger count with the stagger interval between triggers) and
  ignored them.
- **1.13.1** — Fix: instant schedule cards show the right animal count.
- **1.13.0** — Fix: instant schedules can be created, run and edited.

## 1.10.0 – 1.12.0 — schedule editing, guests, UI polish

- **1.12.0** — Add: an **Edit Schedule** button in the Schedules hub's
  select mode.
- **1.11.1** — Fix: edit-schedule follow-ups. The dialog opens large
  enough to show the whole form, the Quick Apply start/end/volume row is
  pre-filled and its edits now apply on save (before, they were ignored
  unless Apply to All was clicked), and the Schedules hub log lists the
  exact edits made.
- **1.11.0** — Change: the edit-schedule dialog is rebuilt on the wizard's
  step 3 and saves its edits. Card labels no longer show grey boxes.
- **1.10.1** — Fix: drop-down lists show every item; Help opens on its
  first topic.
- **1.10.0** — Change: Settings is hidden from guests and Help is now open
  to them (it was disabled when logged out). The schedule wizard validates
  the delivery window before saving (a name, at least one animal, volume
  above zero, end after start, and a window long enough for the summed
  per-cage pulse time) and defaults the staggered window to 1 hour instead
  of 12, as does the edit dialog. The solenoid strategy's fallback now
  defaults to pulse mode (already enforced in production, so no delivery
  change).

## 1.9.x — legacy flow sensor removed, lint gate, UI polish

- **1.9.3** — Fix: calibration buttons fit their row. Tidier wizard
  header; Help's "Creating Schedules" rewritten for the wizard.
- **1.9.2** — Fix: calibration buttons centred; the animals table fills
  its width after a refresh; login prompt and Schedules empty state
  tidied.
- **1.9.1** — Fix: the Delivery hardware-mode help text and the drop-down
  menu.
- **1.9.0** — Change: removed the legacy direct-I²C flow-sensor driver.
  The Teensy UART bridge is the only flow sensor, and a device still set
  to `i2c` falls back to calibration-only mode. The code is now formatted
  and linted with ruff. CONTRIBUTING.md and this changelog added;
  ProjectsController and ScheduleDropArea now take the shared
  DatabaseHandler (one DB handle instead of three).

## 1.8.x — stop-sequence safety + multi-HAT

- **1.8.7** — Fix: the Stop button now ends a running schedule *cleanly*
  in well under a second instead of being force-terminated after a 3 s
  hang. (Root cause: the worker-thread quit signal was queued behind the
  blocked UI thread; switched to a direct connection.)
- **1.8.6** — Fix: a crash in the stop cleanup path (`UnboundLocalError`)
  that prevented the delivery worker from shutting down on Stop.
- **1.8.5** — Fix: creating a staggered schedule failed when the start/end
  time landed on a whole second (no microseconds). Schedule creation now
  parses ISO datetimes robustly.
- **1.8.4** — Internal: temporary timing instrumentation for the Stop
  investigation (removed in 1.8.6).
- **1.8.3** — Fix: Stop now reliably cancels an in-flight delivery instead
  of letting the next chunk start (cancellation token reset moved to
  schedule start; worker cycle loops honor cancellation).
- **1.8.2** — Add: cooperative cancellation in the delivery strategies so
  Stop interrupts a pour promptly.
- **1.8.1** — Fix (safety): on Stop, all relays — including the master
  solenoid — are dropped *first*, before any thread teardown, so the
  hardware can never be left energized if shutdown stalls.
- **1.8.0** — Feature: the Cages tab now paginates by HAT (one tab per
  relay HAT) so multi-HAT setups are fully visible and editable.

## 1.7.x — cleanup, multi-HAT plumbing, update-flow fixes

- **1.7.7** — Fix: changing the relay-HAT count now regenerates the
  cage→relay map (a 2-HAT setup yields 31 cages, not a stale 15).
- **1.7.6** — Fix: the Cages tab now refreshes correctly after a HAT-count
  change (the system controller is wired through to it).
- **1.7.5** — Fix: "Change Relay Hats" updates the Cages tab immediately,
  without an app restart.
- **1.7.4** — Change: simplified the update notifier to the single GitHub
  release-check path; removed the unused legacy local-changelog dialog.
- **1.7.3** — Change: removed a stale ~1.9 MB doc archive from the release
  bundle (smaller, faster updates).
- **1.7.2** — Fix (safety): quitting RRR is now blocked while a delivery
  schedule is running — Stop the schedule first.
- **1.7.1** — Fix: applying an in-app update now reliably loads the new
  version on restart (was occasionally relaunching the old release).
- **1.7.0** — Change: removed unused legacy UI modules (public-surface
  cleanup; no operator-visible behavior change).

## 1.6.x — dead-code cleanup + offline resilience

- **1.6.4** — Change: removed unused/dead code across the app (Tier-0
  cleanup); fixed a latent crash in the "Change Relay Hats" path.
- **1.6.1** — Improve: clearer Slack-status indicator and update-failure
  dialogs (offline-resilience Phase 3).
- **1.6.0** — Add: fail-closed update verification + a network helper so a
  flaky connection can never install an unverifiable bundle (Phase 2).

## 1.5.x — settings persistence + offline groundwork

- **1.5.3** — Add: offline-resilience test harness (Phase 1).
- **1.5.2** — Maintenance release.
- **1.5.1** — Change: Slack credentials moved to a mode-0600 `secrets.json`
  separate from the settings DB (Phase 2.5b).
- **1.5.0** — Change: type-aware settings persistence in SQLite with a
  one-time migration from the legacy `settings.json` (Phase 2.5a).

## 1.0.0 – 1.4.2 — the in-app update system

- **1.4.x** — Update-apply engine, blue-green activation, recovery fixes
  (Phase 2c).
- **1.3.0** — Blue-green release layout under `~/rrr` + data migration
  (Phase 2b).
- **1.2.0** — Centralized data paths via a `paths` module (Phase 2a).
- **1.1.0** — In-app update check + notification banner (Phase 1).
- **1.0.0** — First versioned release; baseline for the update system
  (Phase 0).

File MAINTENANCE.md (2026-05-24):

# MAINTENANCE.md

Release, versioning, and maintenance reference for RRR maintainers.
Companion to [DEVELOPMENT.md](DEVELOPMENT.md) (architecture & how to
develop) and [docs/UPDATE_SYSTEM.md](docs/UPDATE_SYSTEM.md) (design of
the update pipeline). Hard rules live in [CLAUDE.md](CLAUDE.md); this
file is the operator-friendly recipe book.

---

## Contents

1. [When to release (and when not to)](#1-when-to-release-and-when-not-to)
2. [Picking the version number — SemVer for RRR](#2-picking-the-version-number--semver-for-rrr)
3. [Release recipes](#3-release-recipes)
4. [Hard rules](#4-hard-rules)
5. [Verifying a release](#5-verifying-a-release)
6. [Recovery procedures](#6-recovery-procedures)
7. [Branch & commit conventions](#7-branch--commit-conventions)

---

## 1. When to release (and when not to)

A release publishes a `.rrrupdate` bundle that deployed devices can
install via the in-app **Updates** tab. Cutting one means **every device
on the network can pull this code**, so the decision is operational, not
cosmetic.

### ✅ Cut a release when…

| Change | Why |
|---|---|
| Bug fix in delivery, calibration, scheduling, sensor, or relay code | Live animals; ship the fix |
| Behavior change visible to operators (UI text, new tab, new flow) | Operators should pick it up |
| New feature wired into the runtime | What we're shipping |
| Security fix (token handling, file permissions, integrity check) | Always release security fixes |
| Hardware driver fix or new supported board | Production reliability |
| Dependency bump that fixes a real issue | Once vetted |

### ❌ Do **not** cut a release when…

| Change | Why not |
|---|---|
| Pure documentation (README, CLAUDE.md, this file, doc-string typos) | No runtime effect |
| Repo reorganisation, `.gitignore` tweaks, dev tooling | No runtime effect |
| Test-only changes that don't change production code | No runtime effect — *but* CI must still go green |
| Internal refactor whose new code path is not yet called | Land it, ship later when wired up |
| Anything not yet validated on a real Pi | Test first, then release |

**Test-only or doc-only PRs do NOT bump `Project/version.py` and do NOT
get tagged.** Merge to `main` and stop. Devices keep running their
current release; nothing pulls.

### Edge case — "should this be its own release or wait for the next one?"

If the next release is days away and the change isn't urgent, pile on.
If you're not sure, **bias toward a release** — `MINOR`/`PATCH` is cheap
and the in-app update path is well tested. Avoid sitting on fixes that
affect device behavior.

---

## 2. Picking the version number — SemVer for RRR

`Project/version.py` carries `__version__ = "MAJOR.MINOR.PATCH"`. The
git tag must be exactly `v<__version__>` at the tagged commit, or CI
rejects the build (see [`.github/workflows/release.yml`](.github/workflows/release.yml)).

### PATCH bump — `1.6.1 → 1.6.2`

A user-invisible-or-near-invisible **fix** to existing behavior. No new
features, no breaking changes.

| Example | PATCH |
|---|---|
| Off-by-one in cycle timing | ✅ |
| CSV export drops the last row | ✅ |
| Slack indicator shows wrong glyph on a specific error code | ✅ |
| Crash on launch when `settings.json` is missing a key | ✅ |
| Dependency security pin (e.g. `requests` ⇒ patched) | ✅ |
| New UI feature | ❌ — that's MINOR |
| New DB column | ❌ — that's MINOR or MAJOR depending on migration |

### MINOR bump — `1.6.1 → 1.7.0`

A **feature or behavior change** that is backwards-compatible. Devices
on the previous version can install this without operator intervention.

| Example | MINOR |
|---|---|
| New scheduling mode (e.g. "burst") | ✅ |
| New Settings sub-tab | ✅ |
| New sensor driver, opt-in via config | ✅ |
| `apply_update` switched to fail-closed digest verification | ✅ (Phase 2 / v1.6.0) |
| Slack notifier broadens what it catches; new `last_status` attribute | ✅ (Phase 2 / v1.6.0) |
| Pure bug fix | ❌ — that's PATCH |
| DB schema change requiring a one-way migration | ❌ — that's MAJOR |

### MAJOR bump — `1.6.1 → 2.0.0`

A **breaking change** — devices may need explicit operator action, a
hardware change, or a non-trivial migration. Stop and ask whether the
change can be designed backwards-compatible *before* committing to a
MAJOR release.

| Example | MAJOR |
|---|---|
| DB schema change that cannot be auto-migrated | ✅ |
| Change of GPIO pin mapping or hardware protocol | ✅ |
| Drop support for an old Pi model or board revision | ✅ |
| Settings file format change that operators must hand-edit | ✅ (avoid this — provide a migration) |
| Renaming `Project/version.py` or any path the installer hard-codes | ✅ |

Practical signal: **if you're about to add a release-note line that
starts with "Operators must…", it's a MAJOR**.

### When in doubt

- Fix → PATCH.
- New thing → MINOR.
- Forces the operator to do anything → MAJOR.
- If two reasonable people would disagree, pick the *higher* of the two.
  An over-bump is cheap; an under-bump misleads operators about what's
  in a release.

### Pre-releases — `1.7.0-beta`

For risky changes you want to validate on a test Pi before fleet
rollout. Tag as `v1.7.0-beta` (or `-beta.2`, etc). CI publishes it as a
GitHub **pre-release**; the in-app check ignores pre-releases unless the
device is explicitly opted into the beta channel (see
[docs/UPDATE_SYSTEM.md §5.4](docs/UPDATE_SYSTEM.md)).

### Tag history as a sanity check

```
$ git tag --list 'v*' --sort=v:refname
v1.4.1
v1.4.2
v1.5.0   # MINOR — Phase 2.5a settings persistence
v1.5.1   # PATCH — Phase 2.5b secrets file
v1.5.2
v1.5.3   # PATCH — offline-resilience test harness (Phase 1)
v1.6.0   # MINOR — utils.net + fail-closed digest (Phase 2)
v1.6.1   # PATCH — Slack indicator + classified dialogs (Phase 3, arguably MINOR)
```

If a row makes you go "huh, that should have been MINOR not PATCH" —
note it for next time. Past tags are immutable.

---

## 3. Release recipes

### 3a. Standard release — code change shipping to devices

```bash
# 1. clean base
git checkout main
git pull --ff-only origin main

# 2. branch
git checkout -b <type>/<short-slug>          # e.g. fix/calibration-csv-export

# 3. make your code changes; commit incrementally if useful

# 4. bump the version — ALWAYS for a release-bound change
$EDITOR Project/version.py                   # SemVer per §2

# 5. tests must pass locally
pytest

# 6. commit + push + PR
git add -A
git commit -m "<type>(<scope>): one-line summary

Optional body."
git push -u origin <type>/<short-slug>
# open the printed compare URL, create PR, merge on GitHub

# 7. tag and publish — ONLY after the PR is merged into main
git checkout main
git pull --ff-only origin main
git tag v<MAJOR.MINOR.PATCH>                 # MUST equal Project/version.py
git push origin v<MAJOR.MINOR.PATCH>         # point of no return
# CI now builds the bundle, computes SHA256, creates the GitHub Release
```

### 3b. Hotfix on top of an in-flight release

If you've already merged a release-bound PR but haven't tagged yet, and
you spot a bug — fix it on a new branch, merge to `main`, bump
`version.py` once more (PATCH again), then tag the latest commit. The
intermediate "would-have-been-tagged" commit on `main` is just history.

If you've **already pushed the tag**, the bad release is published.
Don't try to undo it — cut a new PATCH on top. See §6.

### 3c. Doc / test-only change

Same as 3a but **skip steps 4 and 7**. No version bump, no tag. The
change lands on `main` and stays there until the next code change cuts
the next release (which will pick this up automatically).

### 3d. Pre-release / beta

```bash
# in version.py
__version__ = "1.7.0-beta"

git tag v1.7.0-beta
git push origin v1.7.0-beta
```

CI flags it as a pre-release. Promote it to stable by tagging `v1.7.0`
on the same (or a newer) commit after validation. Don't forget to
re-bump `version.py` to `1.7.0` before tagging stable.

---

## 4. Hard rules

Restated from [CLAUDE.md](CLAUDE.md) — the ones that matter at release
time:

| # | Rule | What it stops |
|---|---|---|
| H1 | Always branch off `main` — never commit directly to `main` | Bypassed review; partial releases |
| H2 | `git pull --ff-only origin main` *before* tagging | Tagging a stale commit (we did this with v1.6.0 once — recovered in §6) |
| H3 | `Project/version.py` MUST equal the tag (`v` + value) at the tagged commit | CI rejects the build with an explicit error |
| H4 | `git push origin <tag>` publishes a GitHub Release — point of no return | Anything you push, customers can download |
| H5 | Never edit `dist/` or upload release assets by hand | CI is the only writer there |
| H6 | Never commit `settings/settings.json`, `*.db`, or `secrets.json` | Operator data + Slack credentials would leak |
| H7 | Pre-release tag suffix is `-beta` (e.g. `v1.7.0-beta`) | Mixing pre-release into stable; CI uses the suffix to flag |

`git tag` alone is local and reversible. `git push origin <tag>` is
not. Pause before that command.

---

## 5. Verifying a release

After `git push origin v<x.y.z>`:

1. **Open the Actions tab** on GitHub. The "Release" workflow should
   run within seconds. Wait for it to go green (~1–2 min).
2. **Open the Releases page**. The new tag should appear with three
   assets: `rrr-<x.y.z>.rrrupdate`, `rrr-<x.y.z>.rrrupdate.sha256`,
   `latest.json`. The newest stable release gets the **Latest** badge.
3. **Sanity-check `latest.json`** — open it in the browser:
   ```json
   {
     "version": "1.6.1",
     "url": "https://github.com/Corticomics/rodRefReg/releases/download/v1.6.1/rrr-1.6.1.rrrupdate",
     "sha256": "...",
     "min_upgradable_from": "0.0.0",
     "channel": "stable"
   }
   ```
   The `version` field must match the tag; the bundle URL must 200.
4. **On a test Pi**, open RRR → Settings → Updates → "Check for
   updates". The new version should appear within seconds. Click
   "Update now" and watch the apply → restart cycle complete.
5. **Watch the test Pi for ~5 minutes** under a real schedule before
   declaring victory. The launcher's boot sentinel
   ([scripts/runtime/launch.sh](scripts/runtime/launch.sh)) auto-rolls
   back a release that fails to start twice in a row, but you want to
   catch behavior issues *before* the fleet does.

If CI fails: the most common cause is a tag/version mismatch (rule H3).
See §6.4.

---

## 6. Recovery procedures

### 6.1 You tagged the wrong commit — tag not yet pushed

```bash
git tag -d v<x.y.z>
# re-tag on the right commit
git tag v<x.y.z> <correct-sha>
git push origin v<x.y.z>
```

### 6.2 You pushed a bad tag; no Release exists yet (CI rejected it)

This is the v1.6.0 situation we recovered from. CI rejected because the
tag pointed at a commit whose `version.py` was older than the tag name.

```bash
git tag -d v<x.y.z>                          # local
git push origin :refs/tags/v<x.y.z>          # remote (the `:` prefix = delete)
git tag v<x.y.z> <correct-sha>               # re-tag at the commit where version.py == x.y.z
git push origin v<x.y.z>                     # new CI run, this time should pass
```

### 6.3 A bad release IS published and devices may have it

You cannot recall a release; devices may already be running it.

1. **Cut a new PATCH release** with the fix as fast as you can. Bump
   `version.py`, branch, PR, merge, tag, push. Affected devices update
   on their next check (default cadence is silent on launch).
2. If the bug is severe (delivery affected, data loss risk), tell
   operators directly via Slack / email. The Updates tab also has a
   **Revert to previous version** button — operators can click it to
   roll back to the last known-good release.
3. Yank the bad release? `gh release delete v<x.y.z>` removes the
   GitHub Release; the tag stays. Devices that already pulled it keep
   running it until they update. Not a substitute for shipping a fix.

### 6.4 CI rejected the tag with "tag does not match Project/version.py"

The release workflow ([`.github/workflows/release.yml`](.github/workflows/release.yml))
checks `tag_name == "v" + Project/version.py` *at the tagged commit*.
The fix is §6.1 (tag not yet pushed) or §6.2 (tag pushed). Do not edit
`version.py` and force-push — that rewrites history and is worse.

### 6.5 The bundle won't download or verify on a device

The Phase 2 updater (`v1.6.0+`) **refuses to install** an unverifiable
bundle (`utils.net.require_digest` is fail-closed). The dialog says
*"Could not verify the update — the checksum file is unreachable"*.

- 99% of the time: GitHub asset propagation lag. Wait a minute and
  re-check.
- 1% of the time: real corruption. Re-cut the release; the bundle is
  rebuilt deterministically from `git archive HEAD`.

---

## 7. Branch & commit conventions

### Branch names

`<type>/<short-kebab-slug>` — examples:

- `feat/burst-scheduling-mode`
- `fix/calibration-csv-export`
- `refactor/extract-relay-handler`
- `test/coverage-for-secrets`
- `docs/add-maintenance-guide`
- `chore/bump-cryptography`

Phased work that ships across multiple PRs can use a longer prefix:

- `offline-resilience/phase-1-test-harness`
- `offline-resilience/phase-2-net-and-updater`

### Commit message format

Conventional commits, as in [DEVELOPMENT.md § Commit Messages](DEVELOPMENT.md#commit-messages):

```
<type>(<scope>): <one-line summary>

<optional body — wrap at ~72 cols, explain why, not what>

<optional footer>
```

`<type>` ∈ `feat`, `fix`, `refactor`, `test`, `docs`, `chore`,
`style`, `perf`, `ci`. `<scope>` is usually a directory or
component (`secrets`, `updater`, `installer`, `offline`).

For release-bound commits, mentioning the target version helps later
readers:

```
feat(offline): Slack failure indicator + clearer updater dialogs (Phase 3, v1.6.1)
```

### PR conventions

- One concern per PR. If the diff stat starts to look unrelated, split.
- The PR title matches the merge commit's subject (GitHub default).
- Squash-merge is fine for small PRs; merge-commit is fine for phased
  work where individual commits add value to `git log`.
- A release-bound PR's description should call out: what bumped
  `version.py`, what category of change (PATCH/MINOR/MAJOR), and any
  manual validation done on a test Pi.

---

## Cross-references

- [CLAUDE.md](CLAUDE.md) — the hard-rule one-pager (read before tagging)
- [DEVELOPMENT.md](DEVELOPMENT.md) — architecture, modules, hardware,
  dev environment setup
- [docs/UPDATE_SYSTEM.md](docs/UPDATE_SYSTEM.md) — full design of the
  update pipeline (bundle format, blue-green layout, apply engine,
  boot sentinel)
- [README.md](README.md) — user/operator-facing install + quickstart
- [.github/workflows/release.yml](.github/workflows/release.yml) — the
  CI workflow that runs on every `v*` tag push
- [scripts/release/build-bundle.sh](scripts/release/build-bundle.sh) —
  what `git archive`s into the bundle (worth reading once)

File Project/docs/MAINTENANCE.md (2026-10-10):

# MAINTENANCE.md

Release, versioning, and maintenance reference for RRR maintainers.
Companion to [DEVELOPMENT.md](DEVELOPMENT.md) (architecture and how to
develop) and [UPDATE_SYSTEM.md](UPDATE_SYSTEM.md) (design of
the update pipeline). Hard rules live in [CLAUDE.md](../../CLAUDE.md); this
file is the operator-friendly recipe book.

---

## Contents

1. [When to release (and when not to)](#1-when-to-release-and-when-not-to)
2. [Picking the version number — SemVer for RRR](#2-picking-the-version-number--semver-for-rrr)
3. [Release recipes](#3-release-recipes)
4. [Hard rules](#4-hard-rules)
5. [Verifying a release](#5-verifying-a-release)
6. [Recovery procedures](#6-recovery-procedures)
7. [Branch & commit conventions](#7-branch--commit-conventions)

---

## 1. When to release (and when not to)

A release publishes a `.rrrupdate` bundle that deployed devices can
install via the in-app **Updates** tab. Cutting one means **every device
on the network can pull this code**, so the decision is operational, not
cosmetic.

### Cut a release when…

| Change | Why |
|---|---|
| Bug fix in delivery, calibration, scheduling, sensor, or relay code | Live animals; ship the fix |
| Behavior change visible to operators (UI text, new tab, new flow) | Operators should pick it up |
| New feature wired into the runtime | What we're shipping |
| Security fix (token handling, file permissions, integrity check) | Always release security fixes |
| Hardware driver fix or new supported board | Production reliability |
| Dependency bump that fixes a real issue | Once vetted |

### Do **not** cut a release when…

| Change | Why not |
|---|---|
| Pure documentation (README, CLAUDE.md, this file, doc-string typos) | No runtime effect |
| Repo reorganisation, `.gitignore` tweaks, dev tooling | No runtime effect |
| Test-only changes that don't change production code | No runtime effect — *but* CI must still go green |
| Internal refactor whose new code path is not yet called | Land it, ship later when wired up |
| Anything not yet validated on a real Pi | Test first, then release |

**Test-only or doc-only PRs do NOT bump `Project/version.py` and do NOT
get tagged.** Merge to `main` and stop. Devices keep running their
current release; nothing pulls.

### Edge case — "should this be its own release or wait for the next one?"

If the next release is days away and the change isn't urgent, pile on.
If you're not sure, **bias toward a release** — `MINOR`/`PATCH` is cheap
and the in-app update path is well tested. Avoid sitting on fixes that
affect device behavior.

---

## 2. Picking the version number — SemVer for RRR

`Project/version.py` carries `__version__ = "MAJOR.MINOR.PATCH"`. The
git tag must be exactly `v<__version__>` at the tagged commit, or CI
rejects the build (see [`.github/workflows/release.yml`](../../.github/workflows/release.yml)).

### PATCH bump — `1.6.1 → 1.6.2`

A user-invisible-or-near-invisible **fix** to existing behavior. No new
features, no breaking changes.

| Example | PATCH |
|---|---|
| Off-by-one in cycle timing | yes |
| CSV export drops the last row | yes |
| Slack indicator shows wrong glyph on a specific error code | yes |
| Crash on launch when `settings.json` is missing a key | yes |
| Dependency security pin (e.g. `requests` to a patched version) | yes |
| New UI feature | no — that is MINOR |
| New DB column | no — that is MINOR or MAJOR depending on migration |

### MINOR bump — `1.6.1 → 1.7.0`

A **feature or behavior change** that is backwards-compatible. Devices
on the previous version can install this without operator intervention,
or with only a step the set-up guide already required (see "When in
doubt").

| Example | MINOR |
|---|---|
| New scheduling mode (e.g. "burst") | yes |
| New Settings sub-tab | yes |
| New sensor driver, opt-in via config | yes |
| `apply_update` switched to fail-closed digest verification | yes (Phase 2 / v1.6.0) |
| Slack notifier broadens what it catches; new `last_status` attribute | yes (Phase 2 / v1.6.0) |
| Run refuses a schedule until every cage it waters is calibrated — a step HARDWARE_SETUP already required | yes (v1.21.0; see "When in doubt") |
| Pure bug fix | no — that is PATCH |
| DB schema change requiring a one-way migration | no — that is MAJOR |

### MAJOR bump — `1.6.1 → 2.0.0`

A **breaking change** — devices may need explicit operator action, a
hardware change, or a non-trivial migration. Stop and ask whether the
change can be designed backwards-compatible *before* committing to a
MAJOR release.

| Example | MAJOR |
|---|---|
| DB schema change that cannot be auto-migrated | yes |
| Change of GPIO pin mapping or hardware protocol | yes |
| Drop support for an old Pi model or board revision | yes |
| Settings file format change that operators must hand-edit | yes (avoid this — provide a migration) |
| Renaming `Project/version.py` or any path the installer hard-codes | yes |

Practical signal: **if you're about to add a release-note line that
starts with "Operators must…", it's a MAJOR** — unless the line only
enforces something the set-up guide already required of every device
(see "When in doubt").

### When in doubt

- Fix → PATCH.
- New thing → MINOR.
- Forces the operator to do something new → MAJOR.
- Enforces a step a correctly set-up device has already done (v1.21.0
  refusing to water an uncalibrated cage, which the set-up guide already
  required) → MINOR, with a **Before you update** list in the CHANGELOG
  entry so an operator who skipped the step can do it first. Decided for
  v1.21.0 (2026-10-05).
- If two reasonable people would disagree, pick the *higher* of the two.
  An over-bump is cheap; an under-bump misleads operators about what's
  in a release.

### Pre-releases — `1.7.0-beta`

For risky changes you want to validate on a test Pi before fleet
rollout. Tag as `v1.7.0-beta` (or `-beta.2`, etc). CI publishes it as a
GitHub **pre-release**; the in-app check ignores pre-releases unless the
device is explicitly opted into the beta channel (see
[UPDATE_SYSTEM.md §5.4](UPDATE_SYSTEM.md)).

### Tag history as a sanity check

```
$ git tag --list 'v*' --sort=v:refname
v1.4.1
v1.4.2
v1.5.0   # MINOR — Phase 2.5a settings persistence
v1.5.1   # PATCH — Phase 2.5b secrets file
v1.5.2
v1.5.3   # PATCH — offline-resilience test harness (Phase 1)
v1.6.0   # MINOR — utils.net + fail-closed digest (Phase 2)
v1.6.1   # PATCH — Slack indicator + classified dialogs (Phase 3, arguably MINOR)
```

If a row makes you go "huh, that should have been MINOR not PATCH" —
note it for next time. Past tags are immutable.

---

## 3. Release recipes

### 3a. Standard release — code change shipping to devices

```bash
# 1. clean base
git checkout main
git pull --ff-only origin main

# 2. branch
git checkout -b <type>/<short-slug>          # e.g. fix/calibration-csv-export

# 3. make your code changes; commit incrementally if useful

# 4. bump the version — ALWAYS for a release-bound change
#    A release built from several PRs takes one bump: the first release-bound
#    PR sets the version, at the highest level the release needs, and opens
#    its CHANGELOG entry; the release's other PRs add their lines under it.
#    A code fix found while validating the merged release follows §3b.
$EDITOR Project/version.py                   # SemVer per §2

# 4b. add the release to CHANGELOG.md (newest first), as "## <version> — …".
#     Start with a "Before you update" list if operators must do anything,
#     e.g. calibrate cages. Fold any version number that was set on main
#     but never tagged into this entry. The release workflow publishes this
#     entry as the GitHub Release notes, which the in-app Updates tab shows;
#     the test suite fails while version.py names a version with no entry.
$EDITOR CHANGELOG.md

# 5. tests and both lint gates must pass locally (CI runs all three)
pytest
ruff check .
ruff format --check .                        # `ruff format .` fixes layout

# 6. commit + push + PR
git add -A
git commit -m "<type>(<scope>): one-line summary

Optional body."
git push -u origin <type>/<short-slug>
# open the printed compare URL, create PR, merge on GitHub

# 7. tag and publish — ONLY after the PR is merged into main
git checkout main
git pull --ff-only origin main
git tag v<MAJOR.MINOR.PATCH>                 # MUST equal Project/version.py
git push origin v<MAJOR.MINOR.PATCH>         # point of no return
# CI now builds the bundle, computes SHA256, and creates the GitHub Release
# with this release's CHANGELOG.md entry as its notes (step 4b). Check the
# Release page once the workflow is green.
```

### 3b. Hotfix on top of an in-flight release

If you've already merged a release-bound PR but haven't tagged yet, and
you spot a bug — fix it on a new branch, merge to `main`, bump
`version.py` once more (PATCH again), and in `CHANGELOG.md` rename the
untagged heading to the new version, add the untagged version to the
entry's "also carries" line (step 4b folds it) and add a line for the
fix. The suite fails until `CHANGELOG.md` has a `## <new version>`
entry. Then tag the latest commit. The intermediate
"would-have-been-tagged" commit on `main` is just history.

If you've **already pushed the tag**, the bad release is published.
Don't try to undo it — cut a new PATCH on top. See §6.

### 3c. Doc / test-only change

Same as 3a but **skip steps 4, 4b and 7**. No version bump, no
CHANGELOG entry, no tag. The
change lands on `main` and stays there until the next code change cuts
the next release (which will pick this up automatically).

### 3d. Pre-release / beta

```bash
# in version.py
__version__ = "1.7.0-beta"

git tag v1.7.0-beta
git push origin v1.7.0-beta
```

CI flags it as a pre-release. Promote it to stable by tagging `v1.7.0`
on the same (or a newer) commit after validation. Don't forget to
re-bump `version.py` to `1.7.0` before tagging stable. The CHANGELOG
entry can be `## 1.7.0-beta` or just `## 1.7.0`: a pre-release uses its
own entry when there is one, else the stable one.

---

## 4. Hard rules

Restated from [CLAUDE.md](../../CLAUDE.md) — the ones that matter at release
time:

| # | Rule | What it stops |
|---|---|---|
| H1 | Always branch off `main` — never commit directly to `main` | Bypassed review; partial releases |
| H2 | `git pull --ff-only origin main` *before* tagging | Tagging a stale commit (we did this with v1.6.0 once — recovered in §6) |
| H3 | `Project/version.py` MUST equal the tag (`v` + value) at the tagged commit | CI rejects the build with an explicit error |
| H4 | `git push origin <tag>` publishes a GitHub Release — point of no return | Anything you push, customers can download |
| H5 | Never edit `dist/` or upload release assets by hand | CI is the only writer there |
| H6 | Never commit `settings/settings.json`, `*.db`, or `secrets.json` | Operator data + Slack credentials would leak |
| H7 | Pre-release tag suffix is `-beta` (e.g. `v1.7.0-beta`) | Mixing pre-release into stable; CI uses the suffix to flag |

`git tag` alone is local and reversible. `git push origin <tag>` is
not. Pause before that command.

---

## 5. Verifying a release

### Before the tag — smoke test on a test Pi (relay HAT, no water)

A Pi with a relay HAT and no plumbing exercises everything but the
water: the install and launch path, relay addressing, the relay-failure
reporting, the hardware lock, the emergency stop and the UI flows. Run
it on the candidate `main` before tagging, in order; dosing accuracy
still needs the bench validation in
[TOPOLOGY_VALIDATION.md](TOPOLOGY_VALIDATION.md). Leave the relay outputs
unconnected: the relays only click. With no valves, every ledger row
shows the planned volume, which is correct (the app cannot know that no
water moved).

Quit RRR first (close it, or `systemctl --user stop rrr` if it
autostarts): the installer does not stop a running copy, and the
single-instance guard is per version, so a new version would start
beside an old one. `git -C ~/rodRefReg status --short
--untracked-files=no` must print nothing: the installer leaves a
checkout with changes to tracked files as it is and installs its
current commit instead. (A plain `git status` also lists `?? vendor/`,
the relay driver the installer cloned there; that is expected.) Then
install the candidate. The installer
fetches `main` itself and builds the same bundle the tag will, so the
Pi ends up on `~/rrr/releases/<version>` exactly as a device would:

```bash
ssh -Y pi@<test-pi>
cd ~/rodRefReg && ./install.sh -y --branch main
```

A Pi without RRR gets it with the one-line `bootstrap.sh` install in the
[README](../../README.md#1-setting-up-your-system), which clones to
`~/rodRefReg`.

RRR is a PyQt5 window, so use the Pi's desktop, VNC, or `ssh -Y` (from a
Mac it needs XQuartz). Use `-Y`, not `-X`: `-X` is untrusted forwarding,
which refuses new windows 20 minutes after login, so the restarts in
steps 6 and 7 would fail to open RRR. Log in on the Profile tab (Create New
Profile on a fresh database): in guest mode the Settings tab (Priming,
Calibration, Delivery, Updates) is hidden, and Run and Change Relay Hats
are greyed out ("Please log in to use this control"). With the HAT
fitted and I²C enabled (`sudo i2cdetect -y 1` lists it):

1. **Start.** Launch with `~/.local/bin/rrr` from the ssh terminal and
   read that terminal: the start-up lines are printed before the Terminal
   tab exists. Expect `Initialized relay hat stack=0`, `[TOPOLOGY] Valve
   topology: shared_manifold`, and no `Failed to initialize hat stack=…`.
   Do not check this in `journalctl --user -u rrr`: under the service the
   output is buffered, and only the `[TOPOLOGY]` line reaches the journal
   before RRR quits.
2. **Priming.** Settings → Priming: Open Master (relay 16 clicks), Open
   Selected on a cage (its relay clicks), Close Master (both click off).
   Run is greyed out while the session is open and comes back after
   Close Master.
3. **Calibration.** Settings → Calibration: calibrate a cage with 10
   pulses and hear the relay; finish the wizard by entering any measured
   volume (there is no water; 0.3 mL gives 0.03 mL per pulse) so the cage
   counts as calibrated. Start a second run and press Esc while it
   pulses: the clicking stops within about a second, Run is available,
   and no `[VALVE CRITICAL]` line appears.
4. **Run and Stop.** A staggered schedule for one animal on that cage,
   with a window from now to at least two hours ahead: steps 5 to 7 run
   it again, across restarts, and Run refuses it once the window has
   ended (**Expired Schedule**). Drop it in the Schedule Queue and press
   Run; answer Yes to **Schedule Start Time Passed** (asked on every Run
   once the start time is past). The relays click in the pulse rhythm.
   Stop: `[STOP] HARDWARE SAFE: all relays off on every relay HAT`, and
   nothing clicks afterwards.
5. **Emergency stop.** Run the schedule again, then Settings → Priming →
   CLOSE ALL RELAYS: the dialog says the schedule was stopped, Run is
   available, and nothing clicks afterwards.
6. **A missing HAT.** Change Relay Hats to 2 with one HAT fitted: the
   second is now "missing". The Terminal tab shows `Failed to initialize
   hat stack=1: …`, `Relay HAT(s) missing: 1 of 2 initialised; …`,
   `[CLEANUP] CRITICAL: relays NOT confirmed off; …` (expected here) and
   `Relay hats updated to 2 hats.`
   - Run the step-4 schedule and press Stop: the Terminal tab shows
     `[STOP] CRITICAL: not every relay HAT confirmed OFF`, then **Relays
     Not Confirmed Off** and a **Warning** dialog appear. Run is
     available again.
   - A cage on the missing HAT (16 or above) cannot be watered. A
     schedule for an animal on cage 16 is refused at Run with **Valve
     calibration needed** ("Not calibrated: cage 16"). Calibrating cage
     16 with 10 pulses fails at the first pulse: **Calibration Failed**, "The cage 16
     valve did not open at pulse 1 of 10: its relay did not switch",
     with a `[VALVE CRITICAL] calibration of cage 16` line (relay 17
     cannot be switched off either); nothing is saved.
   - Run the step-4 schedule again and press Settings → Priming → CLOSE
     ALL RELAYS: the schedule is stopped first (**Relays Not Confirmed
     Off** and **Warning** again), then **Emergency Stop Failed**. Run
     and Change Relay Hats stay greyed out ("Unavailable while an
     unconfirmed emergency stop is in progress").
   - Restart RRR, log in again, then set the count back to 1 with Change
     Relay Hats (the restart cleared the lock-out).
7. **Topology.** Settings → Delivery → Valve Topology → Independent.
   **Change Valve Topology** offers **Restart RRR** or **Cancel**: Cancel
   first (nothing changes), then Restart RRR. RRR closes and opens again
   by itself. Log in: the step-3 calibration shows **Stale**, the Priming
   panel has no master group, and Open Selected opens a cage directly.
   Calibrate the cage again (only its relay clicks; relay 16 stays
   silent), then Run the step-4 schedule: a delivery clicks only the cage
   relay. Switch back to Shared manifold (RRR restarts again) and
   recalibrate.
8. **Updates tab.** Shows Installed version: <version>, which must be
   the candidate's; press **Check for updates** and it says "You’re up to
   date (version <version>)" (the latest Release is still the previous
   version). The real update path is checked after the tag, below.

### After the tag

After `git push origin v<x.y.z>`:

1. **Open the Actions tab** on GitHub. The "Release" workflow should
   run within seconds. Wait for it to go green (~1–2 min).
2. **Open the Releases page**. The new tag should appear with three
   assets: `rrr-<x.y.z>.rrrupdate`, `rrr-<x.y.z>.rrrupdate.sha256`,
   `latest.json`. The newest stable release gets the **Latest** badge.
3. **Sanity-check `latest.json`** — open it in the browser:
   ```json
   {
     "version": "1.6.1",
     "url": "https://github.com/Corticomics/rodRefReg/releases/download/v1.6.1/rrr-1.6.1.rrrupdate",
     "sha256": "...",
     "min_upgradable_from": "0.0.0",
     "channel": "stable"
   }
   ```
   The `version` field must match the tag; the bundle URL must 200.
4. **On a test Pi**, open RRR → Settings → Updates → "Check for
   updates". The new version should appear within seconds. Click
   "Update now" and watch the apply → restart cycle complete.
   To rehearse the update the lab devices will get, put the test Pi on
   the previous release first, with data of its own, before the tag:
   quit RRR, move the smoke test's data aside (`mv ~/rrr/shared/data
   ~/rrr/shared/data.smoke`), then
   `git -C ~/rodRefReg checkout v<previous> && cd ~/rodRefReg && ./install.sh -y`
   (a checked-out tag stays pinned). Log in, calibrate a cage and run a
   schedule on it, so the update has a database to migrate.
5. **Watch the test Pi for ~5 minutes** under a real schedule before
   declaring victory. The launcher's boot sentinel
   ([scripts/runtime/launch.sh](../../scripts/runtime/launch.sh)) auto-rolls
   back a release that fails to start twice in a row, but you want to
   catch behavior issues *before* the fleet does.

If CI fails: the most common cause is a tag/version mismatch (rule H3).
See §6.4.

---

## 6. Recovery procedures

### 6.1 You tagged the wrong commit — tag not yet pushed

```bash
git tag -d v<x.y.z>
# re-tag on the right commit
git tag v<x.y.z> <correct-sha>
git push origin v<x.y.z>
```

### 6.2 You pushed a bad tag; no Release exists yet (CI rejected it)

This is the v1.6.0 situation we recovered from. CI rejected because the
tag pointed at a commit whose `version.py` was older than the tag name.
The same recovery applies when the Release job fails because
`CHANGELOG.md` has no entry for the version: nothing was published; add
the entry on a branch, merge it, then re-tag the new commit as below.

```bash
git tag -d v<x.y.z>                          # local
git push origin :refs/tags/v<x.y.z>          # remote (the `:` prefix = delete)
git tag v<x.y.z> <correct-sha>               # re-tag at the commit where version.py == x.y.z
git push origin v<x.y.z>                     # new CI run, this time should pass
```

### 6.3 A bad release IS published and devices may have it

You cannot recall a release; devices may already be running it.

1. **Cut a new PATCH release** with the fix as fast as you can. Bump
   `version.py`, branch, PR, merge, tag, push. Affected devices update
   on their next check (default cadence is silent on launch).
2. If the bug is severe (delivery affected, data loss risk), tell
   operators directly via Slack / email. The Updates tab also has a
   **Revert to previous version** button — operators can click it to
   roll back to the last known-good release.
3. Yank the bad release? `gh release delete v<x.y.z>` removes the
   GitHub Release; the tag stays. Devices that already pulled it keep
   running it until they update. Not a substitute for shipping a fix.

### 6.4 CI rejected the tag with "tag does not match Project/version.py"

The release workflow ([`.github/workflows/release.yml`](../../.github/workflows/release.yml))
checks `tag_name == "v" + Project/version.py` *at the tagged commit*.
The fix is §6.1 (tag not yet pushed) or §6.2 (tag pushed). Do not edit
`version.py` and force-push — that rewrites history and is worse.

### 6.5 The bundle won't download or verify on a device

The Phase 2 updater (`v1.6.0+`) **refuses to install** an unverifiable
bundle (`utils.net.require_digest` is fail-closed). The dialog says
*"Could not verify the update — the checksum file is unreachable"*.

- 99% of the time: GitHub asset propagation lag. Wait a minute and
  re-check.
- 1% of the time: real corruption. Re-cut the release; the bundle is
  rebuilt deterministically from `git archive HEAD`.

---

## 7. Branch & commit conventions

### Branch names

`<type>/<short-kebab-slug>` — examples:

- `feat/burst-scheduling-mode`
- `fix/calibration-csv-export`
- `refactor/extract-relay-handler`
- `test/coverage-for-secrets`
- `docs/add-maintenance-guide`
- `chore/bump-cryptography`

Phased work that ships across multiple PRs can use a longer prefix:

- `offline-resilience/phase-1-test-harness`
- `offline-resilience/phase-2-net-and-updater`

### Commit message format

Conventional commits, as in [DEVELOPMENT.md § Commit Messages](DEVELOPMENT.md#commit-messages):

```
<type>(<scope>): <one-line summary>

<optional body — wrap at ~72 cols, explain why, not what>

<optional footer>
```

`<type>` ∈ `feat`, `fix`, `refactor`, `test`, `docs`, `chore`,
`style`, `perf`, `ci`. `<scope>` is usually a directory or
component (`secrets`, `updater`, `installer`, `offline`).

For release-bound commits, mentioning the target version helps later
readers:

```
feat(offline): Slack failure indicator + clearer updater dialogs (Phase 3, v1.6.1)
```

### PR conventions

- One concern per PR. If the diff stat starts to look unrelated, split.
- The PR title matches the merge commit's subject (GitHub default).
- Squash-merge is fine for small PRs; merge-commit is fine for phased
  work where individual commits add value to `git log`.
- A release-bound PR's description should call out: what bumped
  `version.py`, what category of change (PATCH/MINOR/MAJOR), and any
  manual validation done on a test Pi.

---

## Cross-references

- [CLAUDE.md](../../CLAUDE.md) — the hard-rule one-pager (read before tagging)
- [DEVELOPMENT.md](DEVELOPMENT.md) — architecture, modules, hardware,
  dev environment setup
- [UPDATE_SYSTEM.md](UPDATE_SYSTEM.md) — full design of the
  update pipeline (bundle format, blue-green layout, apply engine,
  boot sentinel)
- [README.md](../../README.md) — user/operator-facing install and quickstart
- [.github/workflows/tests.yml](../../.github/workflows/tests.yml) — on every
  PR and push to `main`: ruff (format + lint) and pytest on the runner's
  Python, and pytest again in a Debian Bookworm container (Python 3.11, apt
  PyQt5/pandas, a `--system-site-packages` venv) that mirrors the devices
- [.github/workflows/release.yml](../../.github/workflows/release.yml) — the
  CI workflow that runs on every `v*` tag push (it does not re-run the tests)
- [scripts/release/build-bundle.sh](../../scripts/release/build-bundle.sh) —
  what `git archive`s into the bundle (worth reading once)

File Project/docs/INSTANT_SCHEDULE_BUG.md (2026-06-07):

# Instant-delivery schedules: storage inconsistency (tracked)

**Status:** RESOLVED.
- v1.13.0 — create + run + edit fixed (create writes `schedule_instant_deliveries`,
  the table the runtime reads; instant schedules editable in `ScheduleEditDialog`).
- v1.14.0 — instant execution migrated to `SolenoidFlowStrategy` (was the legacy
  pump-trigger path), so instant delivers with the same pulse/calibration as staggered.
- v1.14.1 — dead code removed: the `schedule_time_instants` method cluster
  (`add_schedule_instant`, `get_pending_schedule_instants`, `mark_instant_completed`,
  `add_instant_schedule`) and the never-instantiated `ScheduleController` /
  `DeliveryQueueController` / `WateringController`. Instant deliveries now live
  solely in `schedule_instant_deliveries`.

The original diagnosis (from v1.11.0) is kept below for historical context; the
referenced legacy methods/tables no longer exist.

## Symptom

Instant-delivery schedules created through the wizard appear to save but
**deliver nothing** when run, because the rows the runtime reads are never
written.

## Root cause

Two different tables are used for "instant" deliveries, and the write path and
the read path disagree:

| Path | Code | Table |
|---|---|---|
| Wizard create (intended) | `ScheduleCreationWizard._create_schedule` instant branch → `add_schedule(schedule)` | `schedule_instant_deliveries` — but `schedule.instant_deliveries` is **empty** (the wizard called `add_animal`, never `add_instant_delivery`), so **no rows** are written |
| Wizard create (actual) | same method → `add_schedule_instant()` per animal | **`schedule_time_instants`** — a table that is **never created** in the schema (`DatabaseHandler.__init__`), so the INSERT raises and is swallowed |
| Runtime read | `run_stop_section.py` / `schedule_drop_area.py` → `get_schedule_instant_deliveries()` | **`schedule_instant_deliveries`** |

Net effect: nothing is written to `schedule_instant_deliveries`, so the runtime
finds zero deliveries. Staggered schedules are unaffected (separate, coherent
tables: `schedule_animals` / `schedule_desired_outputs` /
`schedule_staggered_windows`).

Key references:
- `add_schedule_instant` →
  [database_handler.py](../models/database_handler.py) (`INSERT INTO schedule_time_instants`)
- `get_schedule_instant_deliveries` reads `schedule_instant_deliveries`
- Wizard instant create branch →
  [schedule_wizard.py](../ui/schedule_wizard.py) `_create_schedule`

## Why edit-schedule (v1.11.0) sidesteps it

The rebuilt `ScheduleEditDialog` fully supports **staggered** editing. For
**instant** schedules it shows a short "editing instant schedules isn't
available yet" notice instead of a half-working form, so no edit can land on the
broken storage.

## Planned fix (phased)

- **Phase A — unify instant storage (own PR, MINOR).** Make the wizard write
  real rows to `schedule_instant_deliveries` (populate the schedule via
  `add_instant_delivery`, or call `add_schedule_instant` against the correct
  table). Drop or migrate the orphaned `schedule_time_instants` path. Requires a
  Pi delivery test (instant schedule actually dispenses).
- **Phase B — enable instant editing.** Once storage is coherent, extend the
  edit dialog's instant branch to load/save real instant deliveries and
  re-enable Save (reuse the same `Step3ConfigureParameters` instant mode).

## Test gaps to add with the fix

- A Qt-free DB test that an instant schedule created end-to-end has rows in
  `schedule_instant_deliveries` and that `get_schedule_instant_deliveries`
  returns them.

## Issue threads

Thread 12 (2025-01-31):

Staggered mode individual window bug

zepaulojr1, 2025-01-31:
Currently the stag mode works:
- Iterate through the animals find earliest and latest start, end
- create overall window

Bugs:

Schedule_staggered_windows are being set wrongly in schedules_tab, it is setting all the individual windows with the overall window time

we need to fix the creation of the individual time windows in the DB, change in the business logic to use those windows without interfering in the overall window

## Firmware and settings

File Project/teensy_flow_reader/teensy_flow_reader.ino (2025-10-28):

/*
 * Teensy 4.1 Flow Sensor Reader for RRR - PRODUCTION VERSION
 * ==========================================================
 * 
 * Dedicated I2C sensor reader with UART communication to Pi
 * 
 * Key Features:
 * - Non-blocking I2C operations with timeout
 * - Automatic bus recovery on lockup
 * - Hardware watchdog with strategic feeding
 * - Activity LED for diagnostics
 * - Fast ping response (< 10ms)
 * 
 * Hardware:
 * - Teensy 4.1 connected to Pi via USB (Serial)
 * - SLF3S-0600F flow sensor on Teensy I2C (Wire)
 * - 3.3V power for sensor from Teensy
 * - 2kΩ pullup resistors on SDA/SCL to 3.3V
 * 
 * Communication Protocol:
 * Pi → Teensy: {"cmd":"start","rate":50}
 * Teensy → Pi: {"type":"measurement","flow":123.4,"temp":25.1}
 * 
 * Best Practices:
 * - Follows Sensirion SLF3x datasheet timing specs
 * - Implements I2C clock stretching tolerance
 * - CRC-8 validation for data integrity
 * - Fail-fast error reporting
 */

#include <Wire.h>
#include <ArduinoJson.h>
#include <Watchdog.h>  // Teensy 4.x hardware watchdog

// SLF3S-0600F I2C Configuration
const uint8_t SENSOR_ADDR = 0x08;
const uint16_t START_CMD = 0x3608;  // Start continuous measurement (water mode)
const uint16_t STOP_CMD = 0x3FF9;   // Stop measurement
const uint8_t RESET_ADDR = 0x00;    // General call address for soft reset
const uint8_t RESET_CMD = 0x06;     // Soft reset command

// Communication settings
const unsigned long BAUD_RATE = 115200;
const size_t JSON_BUFFER_SIZE = 256;

// Timing & Safety (per SLF3x datasheet and best practices)
const unsigned long I2C_TIMEOUT_MS = 300;        // Max time for I2C operation
const unsigned long RESET_WAIT_MS = 30;          // Wait after soft reset (datasheet: min 25ms)
const unsigned long BUS_RECOVERY_DELAY_MS = 50;  // Time for bus to settle after recovery
const unsigned long WATCHDOG_FEED_INTERVAL_MS = 500;  // Feed watchdog every 500ms
const uint16_t MAX_CONSECUTIVE_ERRORS = 200;     // Stop streaming after this many errors (increased for rapid pulse testing with EMI)

// I2C Speed (50kHz for maximum reliability with breadboard + EMI from relays)
const uint32_t I2C_CLOCK_HZ = 50000;

// Activity LED (built-in LED for diagnostics)
const int LED_PIN = LED_BUILTIN;
const unsigned long LED_BLINK_MS = 200;  // Blink every 200ms when active

// State variables
bool sensor_running = false;
float sampling_rate = 50.0;  // Hz
unsigned long last_sample_time = 0;
unsigned long sample_interval_us;
uint32_t sample_count = 0;
uint32_t error_count = 0;
uint32_t consecutive_errors = 0;
unsigned long last_watchdog_feed = 0;
unsigned long last_led_toggle = 0;
bool led_state = false;

// Hardware watchdog
Watchdog watchdog;

// JSON buffers
JsonDocument command_doc;
JsonDocument response_doc;

void setup() {
  // Initialize LED for diagnostics
  pinMode(LED_PIN, OUTPUT);
  digitalWrite(LED_PIN, HIGH);  // LED on during startup
  
  // Initialize serial communication with Pi
  Serial.begin(BAUD_RATE);
  // Don't wait forever for serial - Teensy CDC will enumerate when ready
  unsigned long serial_start = millis();
  while (!Serial && (millis() - serial_start < 2000)) {
    // Wait up to 2 seconds for serial connection
  }
  
  // Initialize I2C with conservative settings
  Wire.begin();
  Wire.setClock(I2C_CLOCK_HZ);
  Wire.setTimeout(I2C_TIMEOUT_MS);  // Set I2C timeout (Teensy 4.x feature)
  
  // Initialize hardware watchdog (2 second timeout for faster recovery)
  // This will reset the Teensy if firmware hangs
  // Using 2s instead of 4s for faster hang detection
  watchdog.enable(Watchdog::TIMEOUT_2S);
  last_watchdog_feed = millis();
  
  // Initialize sampling interval
  setSamplingRate(sampling_rate);
  
  // Perform sensor cold-start initialization (reset + warm-up)
  // This ensures sensor is ready with proper calibration
  Wire.beginTransmission(RESET_ADDR);
  Wire.write(RESET_CMD);
  Wire.endTransmission();
  delay(30);  // Reset completion (datasheet: min 25ms)
  watchdog.reset();
  
  // Send a dummy start to initialize sensor, then stop
  Wire.beginTransmission(SENSOR_ADDR);
  Wire.write(START_CMD >> 8);
  Wire.write(START_CMD & 0xFF);
  Wire.endTransmission();
  delay(60);  // Warm-up delay (datasheet: typical 60ms)
  watchdog.reset();
  
  // Stop sensor (idle until commanded)
  Wire.beginTransmission(SENSOR_ADDR);
  Wire.write(STOP_CMD >> 8);
  Wire.write(STOP_CMD & 0xFF);
  Wire.endTransmission();
  delay(10);
  
  // LED off after successful init
  digitalWrite(LED_PIN, LOW);
  
  // Send startup message
  sendStatus("Teensy flow reader initialized (I2C @ " + String(I2C_CLOCK_HZ/1000) + "kHz, watchdog enabled, sensor ready)");
  
  delay(50);
}

void loop() {
  unsigned long now = millis();
  
  // ===== CRITICAL: Feed watchdog regularly =====
  // Feed at start of loop to prevent reset during normal operation
  if (now - last_watchdog_feed >= WATCHDOG_FEED_INTERVAL_MS) {
    watchdog.reset();
    last_watchdog_feed = now;
  }
  
  // ===== Activity LED (diagnostics) =====
  // Blink LED when sensor is running to show firmware is alive
  if (sensor_running) {
    if (now - last_led_toggle >= LED_BLINK_MS) {
      led_state = !led_state;
      digitalWrite(LED_PIN, led_state);
      last_led_toggle = now;
    }
  } else {
    digitalWrite(LED_PIN, LOW);  // LED off when idle
  }
  
  // ===== Process commands from Pi =====
  // Non-blocking serial read
  processCommands();
  
  // ===== Sample sensor if running =====
  if (sensor_running) {
    unsigned long now_us = micros();
    if (now_us - last_sample_time >= sample_interval_us) {
      sampleSensor();
      last_sample_time = now_us;
    }
  }
  
  // ===== Feed watchdog again before loop end =====
  watchdog.reset();
  
  // Small delay to prevent CPU spinning
  delayMicroseconds(100);
}

void processCommands() {
  if (!Serial.available()) return;
  
  // Non-blocking read: read available bytes up to newline or timeout
  String command_str = "";
  unsigned long read_start = millis();
  const unsigned long READ_TIMEOUT_MS = 100;
  
  while (Serial.available() && (millis() - read_start < READ_TIMEOUT_MS)) {
    char c = Serial.read();
    if (c == '\n') break;
    if (c >= 32 && c < 127) {  // Printable ASCII only
      command_str += c;
    }
    if (command_str.length() > 200) {  // Prevent buffer overflow
      sendError("Command too long");
      return;
    }
  }
  
  command_str.trim();
  if (command_str.length() == 0) return;
  
  // Parse JSON command
  DeserializationError error = deserializeJson(command_doc, command_str);
  if (error) {
    sendError("Invalid JSON: " + String(error.c_str()));
    return;
  }
  
  String cmd = command_doc["cmd"];
  
  // ===== FAST PATH: Respond to ping immediately =====
  if (cmd == "ping") {
    sendResponse("pong", "");
    return;  // Don't process further
  }
  
  // ===== Other commands =====
  if (cmd == "start") {
    float rate = command_doc["rate"] | 50.0;
    startSensor(rate);
  }
  else if (cmd == "stop") {
    stopSensor();
  }
  else if (cmd == "status") {
    sendSensorStatus();
  }
  else if (cmd == "reset") {
    resetSensor();
  }
  else {
    sendError("Unknown command: " + cmd);
  }
}

void startSensor(float rate) {
  setSamplingRate(rate);
  
  // Send start command to sensor (skip reset on rapid restarts to avoid watchdog timeout)
  // The sensor maintains its calibration between start/stop cycles
  Wire.beginTransmission(SENSOR_ADDR);
  Wire.write(START_CMD >> 8);    // MSB
  Wire.write(START_CMD & 0xFF);  // LSB
  uint8_t result = Wire.endTransmission();
  
  if (result == 0) {
    // CRITICAL: Minimal delay for I2C transaction to complete
    // Warm-up (60ms) only needed on cold start, not on restart
    // This allows rapid start/stop cycles during pulse testing
    delay(10);  // Brief settling time
    watchdog.reset();
    
    sensor_running = true;
    sample_count = 0;
    error_count = 0;
    consecutive_errors = 0;
    last_sample_time = micros();
    sendStatus("Sensor started @ " + String(rate) + "Hz");
  } else {
    sendError("Failed to start sensor, I2C error: " + String(result));
  }
}

void stopSensor() {
  // CRITICAL: Set flag FIRST to stop sampling loop immediately
  // This prevents race condition where sampleSensor() continues after stop command
  sensor_running = false;
  
  // Send stop command to sensor hardware
  Wire.beginTransmission(SENSOR_ADDR);
  Wire.write(STOP_CMD >> 8);    // MSB  
  Wire.write(STOP_CMD & 0xFF);  // LSB
  Wire.endTransmission();
  
  // Per SLF3x datasheet: Allow sensor to enter idle mode
  delay(10);  // Brief settling time
  
  // Reset LED to OFF state (critical for diagnostics!)
  digitalWrite(LED_PIN, LOW);
  led_state = false;
  
  sendStatus("Sensor stopped (samples:" + String(sample_count) + ", errors:" + String(error_count) + ")");
}

void resetSensor() {
  // Stop sensor first
  if (sensor_running) {
    stopSensor();
    delay(10);
  }
  
  // Perform I2C bus recovery (in case bus is stuck)
  recoverI2CBus();
  
  // Perform soft reset
  Wire.beginTransmission(RESET_ADDR);
  Wire.write(RESET_CMD);
  uint8_t rc = Wire.endTransmission();
  
  // Wait for reset completion
  delay(RESET_WAIT_MS);
  
  // Feed watchdog
  watchdog.reset();
  
  // Clear state
  sensor_running = false;
  sample_count = 0;
  error_count = 0;
  consecutive_errors = 0;
  
  if (rc == 0) {
    sendStatus("Sensor soft reset OK");
  } else {
    sendError("Sensor soft reset failed, I2C error: " + String(rc));
  }
}

// I2C bus recovery - clears bus lockup conditions
void recoverI2CBus() {
  sendStatus("Recovering I2C bus...");
  
  // 1. End current I2C operation
  Wire.end();
  delay(10);
  
  // 2. Reinitialize I2C
  Wire.begin();
  Wire.setClock(I2C_CLOCK_HZ);
  Wire.setTimeout(I2C_TIMEOUT_MS);
  
  // 3. Wait for bus to settle
  delay(BUS_RECOVERY_DELAY_MS);
  
  // 4. Feed watchdog
  watchdog.reset();
  
  sendStatus("I2C bus recovery complete");
}

void setSamplingRate(float rate) {
  sampling_rate = constrain(rate, 1.0, 1000.0);
  sample_interval_us = 1000000.0 / sampling_rate;
}

void sampleSensor() {
  // ===== Request 9 bytes from sensor with timeout =====
  uint8_t bytes_received = Wire.requestFrom(SENSOR_ADDR, (uint8_t)9);
  
  // Check if I2C operation timed out or returned wrong byte count
  if (bytes_received != 9) {
    consecutive_errors++;
    error_count++;
    
    // Report first error and every 50th error to avoid spam
    if (consecutive_errors == 1 || consecutive_errors % 50 == 0) {
      sendError("Sensor read failed: received " + String(bytes_received) + " bytes (consecutive:" + String(consecutive_errors) + ")");
    }
    
    // ===== CRITICAL: Stop streaming after too many consecutive errors =====
    if (consecutive_errors >= MAX_CONSECUTIVE_ERRORS) {
      sendError("Max consecutive errors reached (" + String(MAX_CONSECUTIVE_ERRORS) + "), stopping sensor");
      sensor_running = false;
      
      // Attempt bus recovery
      recoverI2CBus();
    }
    
    return;
  }
  
  // ===== Read 9-byte frame =====
  uint8_t data[9];
  for (int i = 0; i < 9; i++) {
    if (Wire.available()) {
      data[i] = Wire.read();
    } else {
      consecutive_errors++;
      error_count++;
      sendError("Wire.read() failed at byte " + String(i));
      return;
    }
  }
  
  // ===== Verify CRC for flow measurement (bytes 0-2) =====
  uint8_t flow_crc = data[2];
  uint8_t calculated_flow_crc = calculateCRC8(data, 2);
  if (calculated_flow_crc != flow_crc) {
    consecutive_errors++;
    error_count++;
    if (consecutive_errors % 50 == 1) {
      sendError("Flow CRC mismatch (calc:" + String(calculated_flow_crc) + " exp:" + String(flow_crc) + ")");
    }
    return;
  }
  
  // ===== Verify CRC for temperature (bytes 3-5) =====
  uint8_t temp_crc = data[5];
  uint8_t calculated_temp_crc = calculateCRC8(data + 3, 2);
  if (calculated_temp_crc != temp_crc) {
    consecutive_errors++;
    error_count++;
    return; // Skip this sample silently
  }
  
  // ===== Parse raw values =====
  int16_t flow_raw = (data[0] << 8) | data[1];
  int16_t temp_raw = (data[3] << 8) | data[4];
  
  // Handle signed values (two's complement)
  if (flow_raw & 0x8000) flow_raw -= 0x10000;
  if (temp_raw & 0x8000) temp_raw -= 0x10000;
  
  // ===== Apply scaling factors (per SLF3S-0600F datasheet) =====
  float flow_ul_min = flow_raw / 10.0;       // μL/min (scale factor from datasheet)
  float flow_ml_min = flow_ul_min / 1000.0;  // mL/min
  float temp_c = temp_raw / 200.0;           // °C (scale factor from datasheet)
  
  // ===== Send measurement =====
  sendMeasurement(flow_ml_min, temp_c);
  sample_count++;
  
  // Reset consecutive error counter on successful read
  consecutive_errors = 0;
}

uint8_t calculateCRC8(uint8_t* data, uint8_t len) {
  // Sensirion CRC-8: polynomial 0x31, init 0xFF
  uint8_t crc = 0xFF;
  for (uint8_t i = 0; i < len; i++) {
    crc ^= data[i];
    for (uint8_t bit = 0; bit < 8; bit++) {
      if (crc & 0x80) {
        crc = (crc << 1) ^ 0x31;
      } else {
        crc = crc << 1;
      }
    }
  }
  return crc;
}

void sendMeasurement(float flow_ml_min, float temp_c) {
  // CRITICAL: Check if Serial can accept data (non-blocking)
  // If buffer is full, skip this measurement rather than hanging
  if (Serial.availableForWrite() < 100) {
    // Serial buffer nearly full - skip this sample to prevent blocking
    // This prevents firmware hang during high-rate streaming
    return;
  }
  
  response_doc.clear();
  response_doc["type"] = "measurement";
  response_doc["flow"] = serialized(String(flow_ml_min, 4));  // 4 decimal places
  response_doc["temp"] = serialized(String(temp_c, 3));       // 3 decimal places
  response_doc["time"] = millis();
  response_doc["count"] = sample_count;
  
  serializeJson(response_doc, Serial);
  Serial.println();
}

void sendStatus(String message) {
  response_doc.clear();
  response_doc["type"] = "status";
  response_doc["message"] = message;
  response_doc["running"] = sensor_running;
  response_doc["rate"] = sampling_rate;
  response_doc["errors"] = error_count;
  
  serializeJson(response_doc, Serial);
  Serial.println();
}

void sendError(String error_msg) {
  response_doc.clear();
  response_doc["type"] = "error";
  response_doc["error"] = error_msg;
  response_doc["time"] = millis();
  
  serializeJson(response_doc, Serial);
  Serial.println();
}

void sendResponse(String type, String data) {
  response_doc.clear();
  response_doc["type"] = type;
  if (data.length() > 0) {
    response_doc["data"] = data;
  }
  
  serializeJson(response_doc, Serial);
  Serial.println();
}

void sendSensorStatus() {
  response_doc.clear();
  response_doc["type"] = "sensor_status";
  response_doc["running"] = sensor_running;
  response_doc["rate"] = sampling_rate;
  response_doc["samples"] = sample_count;
  response_doc["errors"] = error_count;
  response_doc["consecutive_errors"] = consecutive_errors;
  response_doc["uptime"] = millis();
  response_doc["i2c_clock"] = I2C_CLOCK_HZ;
  
  serializeJson(response_doc, Serial);
  Serial.println();
}

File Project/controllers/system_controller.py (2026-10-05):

import json
import os

from PyQt5.QtCore import QObject, pyqtSignal
from utils import paths


class SystemController(QObject):
    settings_updated = pyqtSignal(dict)
    system_status = pyqtSignal(str)

    def __init__(self, database_handler):
        super().__init__()
        self.database_handler = database_handler
        self.settings = self.load_settings()

    def load_settings(self):
        """Load settings from the DB and the dedicated secrets file.

        On the first run after the v1.5.0 upgrade, values in the legacy
        ``settings.json`` are copied into the DB. On the first run after
        the v1.5.1 upgrade, Slack credentials are extracted into a
        mode-0600 ``secrets.json`` (and removed from the DB). Defaults fill
        any keys still missing. See docs/UPDATE_SYSTEM.md §13.8.
        """
        try:
            self._migrate_legacy_json_if_needed()
            self._ensure_secrets_migrated()
            settings = self._create_default_settings()
            settings.update(self._load_database_settings())
            settings.update(self._load_secrets())
            return settings
        except Exception as e:
            self.system_status.emit(f"Error loading settings: {str(e)}")
            return self._create_default_settings()

    def save_settings(self, settings_dict):
        """Persist managed settings: secrets to ``secrets.json``, the rest to
        the DB; merge everything into ``self.settings``.

        Unmanaged keys (runtime objects, ephemeral state) are kept in memory
        but not persisted — see :meth:`_get_persisted_keys`.
        """
        try:
            self._save_secrets_if_present(settings_dict)
            self._save_database_settings(settings_dict)
            self.settings.update(settings_dict)
            self.settings_updated.emit(self.settings)
        except Exception as e:
            self.system_status.emit(f"Error saving settings: {str(e)}")

    def _create_default_settings(self):
        """Create default settings with proper types"""
        return {
            'num_hats': 1,
            'slack_token': '',
            'channel_id': '',
            'min_trigger_interval_ms': 500,
            'cycle_interval': 3600,
            'stagger_interval': 0.5,
            'hardware_mode': 'solenoid',  # default to solenoid; UI can switch to pump
            'global_master_relay_id': 16,
            'i2c_bus': 3,  # Default to dedicated flow sensor bus (GPIO 12/13)
            'flow_sensor_type': 'uart',  # 'i2c' or 'uart' (Teensy)
            'uart_port': self._detect_initial_teensy_port(),  # Auto-detected Teensy USB port
            'flow_sampling_hz': 50.0,
            'predictive_close_ms': 10.0,
            'residual_check_ms': 200.0,
            'residual_flow_threshold_ml_min': 1.0,
            'max_consecutive_sensor_errors': 10,
            'cage_relays': {},
            # Dose rounding policy: nearest whole pulse unless the operator
            # opts into rounding up. Deliberately NOT in the force-merged
            # pulse_mode_settings block (ensure_solenoid_defaults), which
            # would reset the choice on every start.
            'round_doses_up': False,
            # Valve topology: 'shared_manifold' (master valve + manifold, the
            # production rig) or 'independent' (one syringe and valve per
            # animal, no master). Read by utils.topology; like round_doses_up
            # it is kept out of the force-merged pulse block below.
            'valve_topology': 'shared_manifold',
            'debug_mode': False,
            'log_level': 2,
            'log_level_map': {0: 'DEBUG', 1: 'INFO', 2: 'WARNING', 3: 'ERROR', 4: 'CRITICAL'},
        }

    def _get_persisted_keys(self):
        """Every setting persisted to the SQLite system_settings table.

        Anything else lives in self.settings in memory only — useful for
        runtime objects (e.g. relay_unit_manager) and ephemeral state.
        Single source of truth as of v1.5.0; replaces the prior split
        between ``_get_json_settings_keys`` and ``_get_db_settings_keys``.
        """
        return {
            # Note: slack_token + channel_id are NOT here — they live in the
            # dedicated mode-0600 secrets.json since Phase 2.5b.
            'num_hats',
            'hardware_mode',
            'global_master_relay_id',
            'i2c_bus',
            'flow_sensor_type',
            'uart_port',
            'flow_sampling_hz',
            'predictive_close_ms',
            'residual_check_ms',
            'residual_flow_threshold_ml_min',
            'max_consecutive_sensor_errors',
            'cage_relays',
            # Pulse-mode persistence (Parker Series 3)
            'use_pulse_delivery',
            'pulse_width_ms',
            'pulse_settling_ms',
            'max_pulses_per_delivery',
            'max_pulse_delivery_time_s',
            # Dose rounding policy (v1.19.0): round every dose up to the
            # next whole pulse instead of to the nearest one.
            'round_doses_up',
            # Valve topology (v1.20.0): shared_manifold | independent.
            'valve_topology',
            'debug_mode',
            'log_level',
            # Scheduler tuning
            'min_trigger_interval_ms',
            'cycle_interval',
            'stagger_interval',
            # UI (silently dropped pre-v1.5.0 because it was missing from the
            # JSON key list; managed properly from this release on)
            'theme',
        }

    def _get_setting_type(self, key):
        """Define type mapping for settings"""
        type_map = {
            'num_hats': int,
            'min_trigger_interval_ms': int,
            'cycle_interval': int,
            'stagger_interval': float,
            'debug_mode': bool,
            'log_level': int,
            'slack_token': str,
            'channel_id': str,
            'hardware_mode': str,
            'global_master_relay_id': int,
            'i2c_bus': int,
            'flow_sampling_hz': float,
            'predictive_close_ms': float,
            'residual_check_ms': float,
            'residual_flow_threshold_ml_min': float,
            'max_consecutive_sensor_errors': int,
            # Pulse-mode types
            'use_pulse_delivery': bool,
            'pulse_width_ms': int,
            'pulse_settling_ms': int,
            'max_pulses_per_delivery': int,
            'max_pulse_delivery_time_s': float,
            'round_doses_up': bool,
            'valve_topology': str,
        }
        return type_map.get(key, str)

    # --- Auto-detect helpers (used by UI) ---
    def detect_hats(self):
        """Attempt to detect number of relay HATs by probing stack IDs 0..7.
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

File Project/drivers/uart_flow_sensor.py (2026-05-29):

#!/usr/bin/env python3
"""
UART Flow Sensor Driver for RRR
===============================

Communicates with Teensy 4.1 flow sensor reader via UART/Serial.
Provides the same interface as the I2C flow sensor driver for seamless integration.

Hardware Setup:
- Teensy 4.1 connected to Pi via USB
- SLF3S-0600F sensor connected to Teensy I2C
- Teensy firmware: teensy_flow_reader.ino

Protocol:
Pi → Teensy: {"cmd":"start","rate":50}
Teensy → Pi: {"flow":123.4,"temp":25.1,"time":1234567890}
"""

from __future__ import annotations

import asyncio
import fcntl
import json
import logging
import os
import threading
import time
from dataclasses import dataclass
from queue import Empty, Queue
from typing import AsyncIterator, Optional, Tuple

try:
    import serial

    SERIAL_AVAILABLE = True
except ImportError:
    SERIAL_AVAILABLE = False
    serial = None


class TeensyUnavailableError(ConnectionError):
    """Raised when Teensy is not responding to communication attempts."""

    pass


@dataclass
class FlowSample:
    flow_ml_min: float
    temperature_c: float


class UARTFlowSensor:
    """
    UART-based flow sensor driver for Teensy 4.1 integration.

    Provides same interface as I2C driver for seamless replacement.
    Handles serial communication, JSON protocol, and data buffering.
    """

    def __init__(
        self,
        port: str = '/dev/ttyACM0',
        sampling_hz: float = 50.0,
        zero_offset_ml_min: float = 0.0,
        span_scale: float = 1.0,
        baud_rate: int = 115200,
        timeout: float = 1.0,
    ) -> None:
        if not SERIAL_AVAILABLE:
            raise ImportError("pyserial not available. Install with: pip install pyserial")

        self.port = port
        self.sampling_hz = sampling_hz
        self.zero_offset = zero_offset_ml_min
        self.span_scale = span_scale
        self.baud_rate = baud_rate
        self.timeout = timeout

        self._serial = None
        self._running = False
        self._reader_thread = None
        self._data_queue = Queue(maxsize=100)
        self._latest_sample = None
        self._sample_count = 0
        self._error_count = 0

        self._logger = logging.getLogger(self.__class__.__name__)

        # Connection management
        self._connected = False
        self._last_ping = 0
        self._ping_interval = 10.0  # seconds (reduce chatter during delivery)
        self._pings_suspended = False
        self._reads_suspended = False
        self._recovering = False
        self._i2c_error_count = 0

        # Frame activity monitoring (detect firmware hangs)
        self._last_frame_time = 0
        self._frame_timeout_s = (
            10.0  # No frames for 10s = potential hang (increased for rapid pulse testing)
        )

    def start(self) -> None:
        """Start sensor and begin continuous reading.

        Best Practices:
        - Fail-fast: Verify streaming is active before returning
        - Resource validation: Confirm reader thread is producing data
        - Clear error messages: Report specific failure modes

        Raises:
            TeensyUnavailableError: If sensor doesn't stream within timeout
            ConnectionError: If serial connection fails
        """
        try:
            self._logger.info(
                f"[UART] Starting flow sensor on {self.port} at {self.sampling_hz} Hz"
            )

            self._connect()
            self._logger.info(f"[UART] Connection established to {self.port}")

            self._start_sensor()
            self._logger.info(f"[UART] Sensor start command sent")

            self._running = True

            # Start reader thread
            self._reader_thread = threading.Thread(target=self._reader_loop, daemon=True)
            self._reader_thread.start()
            self._logger.info(f"[UART] Reader thread started")

            # CRITICAL: Verify streaming is active (fail-fast principle)
            # Don't return success until we've confirmed measurements are arriving
            self._logger.info(f"[UART] Verifying stream health...")
            verification_timeout_s = 5.0
            min_frames_required = 5  # ~0.5s at 10 Hz, ~0.1s at 50 Hz

            if not self.wait_for_frames(
                min_frames=min_frames_required, timeout_s=verification_timeout_s
            ):
                error_msg = (
                    f"Stream verification failed: No measurements received within {verification_timeout_s}s. "
                    f"Expected {min_frames_required} frames. "
                    f"Sample count: {self._sample_count}, Error count: {self._error_count}. "
                    f"Check: 1) I²C wiring (SDA/SCL/GND), 2) Pullup resistors (2kΩ), 3) Teensy firmware loaded."
                )
                self._logger.error(f"[UART] {error_msg}")
                self.stop()
                raise TeensyUnavailableError(error_msg)

            self._logger.info(
                f"[UART] Stream health verified ({self._sample_count} measurements received)"
            )
            self._logger.info(
                f"[UART] Flow sensor fully initialized on {self.port} at {self.sampling_hz} Hz"
            )

        except TeensyUnavailableError:
            # Re-raise sensor-specific errors without wrapping
            raise
        except Exception as e:
            self._logger.error(f"[UART] Failed to start flow sensor: {e}", exc_info=True)
            self.stop()
            raise

    def stop(self) -> None:
        """Stop sensor and close connection."""
        self._running = False

        if self._serial and self._serial.is_open:
            try:
                # Clear input buffer to ensure stop command is seen
                try:
                    self._serial.reset_input_buffer()
                except Exception:
                    pass

                self._send_command({"cmd": "stop"})

                # CRITICAL: Wait for firmware to process stop and turn off LED
                # At 20 Hz sampling, worst case is 50ms between loop iterations
                # Plus 10ms sensor settling time = 60ms minimum
                time.sleep(0.15)  # 150ms to ensure complete stop
            except Exception:
                pass

        if self._reader_thread and self._reader_thread.is_alive():
            self._reader_thread.join(timeout=1.0)

        if self._serial:
            try:
                self._serial.close()
            except Exception:
                pass
            self._serial = None

        self._connected = False
        self._logger.info("UART flow sensor stopped")
        # Release inter-process lock
        self._release_lock()

    def _connect(self) -> None:
        """Establish serial connection to Teensy with robust retry logic.
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

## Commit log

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2025-05-08 Revert "Merge pull request #41 from Corticomics/version-beta-0.01"
    This reverts commit f15805286a54e79caabf5bc31d3233f9a5c8c7b1, reversing
    changes made to 72076549a236cd21ff620fb0497749470a0b2843.
    [relay_worker.py]
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2025-09-24 usb stability check since i keep getting IO error after successfully starting it on ACM1
    [uart_flow_sensor.py]
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2025-09-25 Fixed reconnection attr bug, added input flush before ping, extended init delay, added port autodetect on failure, and hardened sensor reads.
    [uart_flow_sensor.py]
2025-09-25 stream gating (require frames before opening valves), suspended pings around valve ops, flushed before pings, extended reconnect waits, stop→start with backoff, auto-detect on port flip, and an I2C r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
    [uart_flow_sensor.py]
2025-09-27 reorder the suspend-reads/pings to happen after ensure_streaming in the strategy, and fix a minor indentation issue in the UART reader loop so the read suspension check runs reliably.
    [uart_flow_sensor.py]
2025-10-05 Pi's pyserial script opens the serial port but doesn't wait long enough for Teensy to complete USB re-enumeration.
    [test_sensor_wiring.py, uart_flow_sensor.py]
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2025-10-07 Fix Settings Key Mismatch (uart_port consistency) Fix Test Connection port file lock when testing teensy
    [SettingsTab.py, uart_flow_sensor.py]
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2025-10-17 Implemented **deterministic stream health verification** using fail-fast principles and idempotent initialization patterns.
    [relay_worker.py, uart_flow_sensor.py]
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2025-11-10 Add per-valve calibration system and tools
    Implements empirical per-valve calibration for solenoid valves, including new database tables, API methods, and a CLI calibration tool. Updates relay worker and strategy factory to support per-valve calibration lookup, and refactors solenoid flow strategy to use full flow curve integration and adaptive correction. Adds quick start and detailed calibration documentation.
    [CalibrationWizard.py, SettingsTab.py, relay_worker.py]
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2025-11-10 Fix indentation and update hardware imports
    Corrects indentation errors in solenoid_flow_strategy.py and updates import paths and initialization logic for relay and solenoid controllers in CalibrationWizard.py to use drivers.solenoid_controller and gpio.gpio_handler.RelayHandler.
    [CalibrationWizard.py]
2025-11-11 Improve calibration save robustness and UI feedback
    Enhanced defensive checks, error logging, and transaction safety in CalibrationWizard's save logic. Success and error messages are now handled within the wizard to prevent duplicate dialogs in SettingsTab, improving user experience and reliability.
    [CalibrationWizard.py, SettingsTab.py]
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2025-11-11 Improve calibration wizard closing and result handling
    CalibrationWizard now uses QTimer to delay dialog closing, ensuring Qt events finish before closing and providing robust fallback methods. SettingsTab adds detailed logging, error handling, and schedules post-calibration operations with QTimer to ensure UI stability and proper feedback after calibration.
    [CalibrationWizard.py, SettingsTab.py]
2025-11-11 Add diagnostic launch scripts and enhance calibration logging
    Added RUN_WITH_FULL_DIAGNOSTICS.sh and run_with_diagnostics.sh for comprehensive diagnostic launching and logging. Improved error logging and debug output in CalibrationWizard and SettingsTab to aid troubleshooting, and updated calibration table UI with clearer status and action icons.
    [CalibrationWizard.py, SettingsTab.py]
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2025-11-12 Refactor UI styling to use object names and properties
    Replaced inline style sheets in UI components with object names and custom properties for more maintainable and themeable styling. Updated dark and light QSS files to support new selectors and improved visuals for buttons, group boxes, lists, and wizard elements. Enhanced layout spacing and margins for better consistency across widgets.
    [CalibrationWizard.py]
2025-11-15 Refactor UI styling to use QSS and properties
    Replaced inline widget stylesheets with QSS-based styling using object names and properties for consistency and maintainability. Updated PrimingControlWidget and SettingsTab to set style properties instead of calling setStyleSheet directly. Added new QSS rules for help text, status labels, and form labels in both dark and light themes. Improved layout and grouping in SettingsTab for better visual structure.
    [PrimingControlWidget.py, SettingsTab.py]
2025-11-15 Improve calibration table layout and QGroupBox styling
    Reduced calibration table row height, set maximum table height, and added spacing to prevent button overlap in SettingsTab.py. Made action buttons more compact. Updated dark and light QSS themes for better QGroupBox and help text readability, and added distinct styling for nested QGroupBox elements.
    [SettingsTab.py]
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2025-11-15 Add CompactButton style for action buttons
    Replaced fixed height with objectName 'CompactButton' for action buttons in SettingsTab.py to enable targeted styling. Added CompactButton styles to both dark and light QSS files for consistent compact appearance in action rows.
    [SettingsTab.py]
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2025-11-17 Implement auto-save for settings and update UI themes
    Replaces manual 'Save All Settings' button with automatic, debounced persistence of settings on change. Updates SettingsTab.py to connect all relevant widgets to auto-save handlers and removes the manual save logic. Also enhances both dark and light QSS themes for modern aesthetics, improved depth, and better visual hierarchy.
    [SettingsTab.py]
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2025-11-17 Add SafeSpinBox widgets to prevent accidental value changes
    Introduces SafeSpinBox and SafeDoubleSpinBox classes that disable scroll wheel changes unless the widget is focused, improving lab safety and data integrity. Updates SettingsTab to use these widgets for all spinbox controls. Adds relevant comments and usage guidance in the new safe_spinbox.py module.
    [SettingsTab.py]
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2025-12-24 Revert "feat(perf): optimize startup with splash screen and glassmorphism login"
    This reverts commit 87267fd42c32a304befc620460af5e5a057730c3.
    [SettingsTab.py]
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2025-12-27 fix(wizard): capture schedule_id return value from add_staggered_schedule
    Bug: add_staggered_schedule() returns schedule_id but doesn't set it on the
    schedule object. The wizard was checking schedule.schedule_id which was None.
    Fix: Capture the return value:
    schedule_id = self._database_handler.add_staggered_schedule(schedule)
    Also includes:
    - SettingsTab.py: null-check for login_system before calling is_logged_in()
    (fixes AttributeError when login_system is None)
    [SettingsTab.py]
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2025-12-28 feat(ui): dynamic layout and compact execution monitor
    Improves screen space usage and fixes execution monitor visibility:
    1. MaterialCard (ScheduleProgressTracker):
    - Removed Sensor/Pulses row for more compact cards
    - Reduced padding (15px → 10px) and spacing (10 → 6)
    - Removed sensor_health tracking and related methods
    2. Dynamic Terminal/Execution Monitor layout:
    - When switching to Execution Monitor, left pane expands (3:1)
    - When on Terminal, projects section expands (1:3)
    - Added _on_terminal_tab_changed() handler
    3. Super Mode button moved to Settings:
    - Created _create_mode_toggle() in SettingsTab
    - Added mode status label
    - Updates state on login/lo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
    [SettingsTab.py]
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2025-12-28 fix(settings): update User Mode state when tab becomes visible
    Bug: User Mode section showed 'Guest' even when logged in because
    the state was only set at init time before login occurred.
    - Override showEvent() to refresh mode state when Settings tab opens
    - Connect tab_widget.currentChanged to refresh when General tab selected
    - Mode state now updates dynamically based on current login status
    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
    [SettingsTab.py]
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2026-01-10 refactor: Remove duplicate Cages tab from Settings
    Removed:
    - Cages tab from Settings (was using CageManagerWidget)
    - _create_cage_manager_tab() method
    - CageManagerWidget import (no longer used)
    - Cage refresh logic in _on_subtab_changed
    Reason:
    - Duplicate functionality - cage naming also available in Projects Section
    - Projects Section CagesVisualizationTab is more intuitive (visual layout)
    - Only 15 cages - table-based management is overkill
    - Settings should be for configuration, not data management
    General tab index updated from 4 to 3 accordingly.
    [SettingsTab.py]
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2026-01-10 perf: Lazy hardware init on worker thread, fix signal connections
    PROBLEM: Previous background thread approach broke Qt signal connections.
    QObject creation and signal connections must be on GUI thread.
    SOLUTION: Hybrid approach
    1. run_program_callback runs on GUI thread (for proper signal setup)
    2. Slow hardware init moved to _initialize_hardware() method
    3. _initialize_hardware() called in run_cycle() on WORKER thread
    This means:
    - __init__() is fast (< 50ms) - just sets flags, no hardware
    - run_cycle() does lazy init on worker thread (5-10s allowed)
    - GUI stays responsive, progress cards update properly
    Moved to _initialize_hardware() (runs on worker thread):
    - create_flow_sensor() - S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
    [relay_worker.py]
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2026-01-14 fix: Tab headers readable, remove Priming activity log
    Tab Header Fixes (app-light.qss & app-dark.qss):
    - Reduced padding: 10px 20px → 8px 16px
    - Added min-width: 70px to ensure text fits
    - Reduced font-size: 13px → 12px for compactness
    - Added qproperty-expanding: false to prevent premature scrolling
    Priming Tab Improvements (PrimingControlWidget.py):
    - Removed duplicate Activity Log widget
    - All priming messages now go to main Terminal tab
    - Cleaner UI with less redundancy
    - Updated _log_message to use print_callback only
    - Removed unused QTextEdit import
    This ensures all tab headers (Terminal, Schedules, Animals,
    Wizard, Cages, Settings, Profile, Help, Delivery, Calibration,
    Priming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
    [PrimingControlWidget.py]
2026-01-14 fix: Calibration table column widths and button visibility
    Column Width Fixes:
    - Cage column: Fixed 70px width
    - Status column: Fixed 120px (fits '[X] Not Calibrated')
    - Volume/Pulse: Stretch to fill remaining space
    - Action column: Fixed 100px for buttons
    Button Fixes:
    - Removed maxWidth constraint (was 95px, too small)
    - Set minWidth to 90px for reliable text display
    - Increased button height: 26px → 28px
    - Increased row height: 36px → 40px for button accommodation
    All text now fully visible: Status shows '[X] Not Calibrated'
    and buttons show 'Calibrate'/'Recalibrate' in full.
    [SettingsTab.py]
2026-01-14 feat: Display custom cage names in Calibration table
    Database Integration:
    - Fetch cage names using get_all_cage_names() (batch query)
    - Display format: 'N: CustomName' or 'Cage N' if no custom name
    - Added tooltip showing cage ID and relay mapping
    Column Optimizations:
    - Cage column: Now stretches to fit custom names
    - Status: Fixed 115px
    - mL/Pulse: Fixed 80px (header shortened)
    - CV%: Fixed 65px (header shortened)
    - Date: Fixed 85px
    - Action: Fixed 95px
    Best Practices:
    - Batch database query (N+1 prevention)
    - Left-aligned cage names for readability
    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
    [SettingsTab.py]
2026-01-14 feat: Auto-sync cage names across tabs, fix column widths
    Cage Name Synchronization:
    - Added cage_names_updated signal to CagesVisualizationTab
    - Signal emitted when any cage name is saved to database
    - Connected to SettingsTab.refresh_calibration_table() in gui.py
    - Observer pattern ensures all tabs stay in sync
    Column Width Optimizations:
    - Cage: Fixed 100px (narrower, still shows custom names)
    - Status: Stretch to fill space
    - mL/Pulse: Fixed 70px (compact)
    - CV%: Fixed 55px (compact)
    - Date: Fixed 80px (compact)
    - Action: Fixed 90px (fits button cleanly)
    - Observer pattern via Qt signals for loose coupling
    - Single source of truth (database)
    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
    [SettingsTab.py]
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2026-05-17 feat: in-app update check + notification (Phase 1)
    Phase 1 of the update system (docs/UPDATE_SYSTEM.md): notify-only. The app
    now tells operators when a newer release exists; it does not download or
    apply anything yet.
    - utils/updater.py: background-thread check against the GitHub Releases API,
    SemVer comparison, silent-fails when offline
    - ui/update_notifier.py: startup check; shows a dismissable banner on the
    main window when an update is available (the legacy ui_updated.json
    dialog is preserved alongside it)
    - ui/UpdatesTab.py: a Settings > Updates panel showing the installed
    version with a manual "Check for updates" button
    - gui.py: window title now shows the version; hosts the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
    [SettingsTab.py]
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2026-05-20 refactor(secrets): move Slack credentials to mode-0600 secrets.json (Phase 2.5b, v1.5.1)
    Phase 2.5b of the update system (docs/UPDATE_SYSTEM.md §13.8). Slack
    credentials now live in a dedicated mode-0600 secrets.json next to the
    database -- never in the DB, never in git -- so a leaked database backup
    or accidental commit cannot expose the token.
    - utils/secrets.py: tempfile.mkstemp + os.replace atomic writer (mkstemp
    yields 0600 on POSIX); get_credentials swallows malformed input so a
    hand-edited typo cannot brick startup.
    - utils/paths.py: new secrets_path() resolving to $RRR_DATA/secrets.json
    (or Project/secrets.json on dev clones).
    - models/database_handler.py: new delete_system_s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
    [system_controller.py]
2026-05-22 test(offline): add offline-resilience characterization harness (Phase 1, v1.5.3)
    Phase 1 of the offline-resilience plan. Locks in the current behaviour of
    the update checker and the Slack notifier under network failure, with no
    production code changes — a safety net for the Phase 2/3 hardening.
    - conftest: `offline` fixture simulating DNS failure for every host
    (socket.getaddrinfo), reusable by any test needing a netless device.
    - test_updater_offline.py: fetch_latest degrades to None when offline
    (connection error, DNS failure, timeout, malformed JSON); apply_update
    off-device and corrupt-bundle paths.
    - test_notifications_offline.py: a Slack API failure falls back to the
    local p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
    [SettingsTab.py]
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2026-05-24 feat(offline): Slack failure indicator + clearer updater dialogs (Phase 3, v1.6.1)
    Phase 3 of the offline-resilience plan — the UX polish phase. Three small,
    focused changes; no production behaviour outside the GUI changes.
    NEW — Project/utils/slack_status.py
    Pure formatter for NotificationHandler.last_status (added in Phase 2).
    Returns (icon, message) with operator-readable troubleshooting per known
    Slack error code: token_revoked / invalid_auth / not_authed -> "re-create
    the bot, paste a fresh token"; channel_not_found / is_archived -> "check
    the Channel ID, invite the bot"; missing_scope -> "add chat:write";
    rate_limited -> "resumes automatically"; network/connection/time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
    [SettingsTab.py]
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2026-05-26 chore(audit): Phase 1 Tier-0 dead-code deletions (v1.6.4)
    Removes 14 unreferenced files (zero callers verified fresh on main)
    plus a latent crash in main.change_relay_hats.
    UI orphans (no imports anywhere; not in ui/__init__.py):
    - advanced_settings.py, RelayContainer.py
    - LoginDialog.py (superseded by login_gate_widget.py)
    - ProfileDialog.py (superseded by UserTab.py)
    - cage_manager_widget.py (superseded by CagesVisualizationTab)
    - drag_drop_container.py
    - interval_settings.py
    - schedule_creation_widget.py
    - edit_schedule_dialog.py (superseded by schedules_hub.ScheduleEditDialog)
    Build/runtime cruft:
    - main.spec (no PyInstaller in deps; release uses git archive)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
    [teste3.xlsx]
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2026-05-28 docs(comments): trim stale test-file refs from production code
    Three production files cited hardware-diagnostic test scripts as if
    they were authoritative implementation references — inviting future
    readers to chase dead breadcrumbs into Project/tests/test_*.py (which
    are operator-diagnostic CLIs, not authoritative spec).
    Rewords without changing semantics:
    - ui/CalibrationWizard.py:49 — drop "test_dialog_crash.py proves this";
    keep the actual rule (use default QDialog, no custom window flags,
    it crashed the parent app before this fix).
    - drivers/teensy_serial_protocol.py — 5 occurrences across module
    docstring, class docstring, and method docstrings of "from
    test_sensor_wiri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
    [CalibrationWizard.py, teensy_serial_protocol.py]
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2026-05-28 fix(safety): cancellation reset semantics + worker-loop cancel check (v1.8.3)
    v1.8.2 made Stop safe but the Pi log proved it still fell through to
    thread.terminate() ("Worker did not exit in 3000ms"). Cooperative
    cancellation was set but not honored in time. Two real gaps, both fixed:
    GAP 1 — per-chunk clear wiped the cancel.
    SolenoidFlowStrategy.deliver() cleared the cancel token at the top of
    EVERY call (once per delivery chunk). The staggered cycle calls deliver()
    once per 0.2mL chunk via _handle_delivery -> run_until_complete. A cancel
    the GUI set between chunks was wiped by the next chunk's entry-clear, so
    that chunk ran to completion. Fix: deliver() no longer clears; it returns
    Fals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
    [relay_worker.py]
2026-05-28 chore(diag): [TIMING] phase markers for the Stop sequence (v1.8.4)
    Diagnostic-only. v1.8.2 and v1.8.3 both failed to make Stop exit
    cleanly — terminate() still fired after the 3s wait — and I've been
    diagnosing from logs without hard timing. This adds monotonic-clock
    [TIMING] markers at every phase boundary so ONE Pi Stop-test reveals
    exactly where the time goes, instead of another speculative fix.
    Markers (all share one process monotonic clock, directly comparable
    across the GUI and worker threads):
    GUI thread:
    - worker.request_cancel (T0: operator pressed Stop)
    - stop_sequence already logs "exited cleanly in Nms" / "did not
    exit in 3000ms" (the wait outcome)
    w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
    [relay_worker.py]
2026-05-29 fix(safety): stop() UnboundLocalError that forced terminate() (v1.8.6)
    The v1.8.4 [TIMING] instrumentation revealed the truth AND introduced a
    crash. Reading the monotonic timestamps from the Pi:
    worker.request_cancel 24608.460
    pulse loop SAW CANCEL 24608.596 (+136 ms)
    deliver() returned False 24608.618 (+158 ms)
    Cooperative cancellation WORKS — the delivery loop bailed in 136 ms.
    That was never the problem. The problem was at the end:
    UnboundLocalError: cannot access local variable 'time'
    at relay_worker.py stop(): print(f"... {time.monotonic()} ...")
    RelayWorker.stop() contains an inner `import time` (for time.sleep(0.5)
    in the flow-sensor stop secti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
    [relay_worker.py]
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2026-05-29 style: ruff format + import-sort across Project/ + CI gate (3.7b-1)
    Phase 3.7b-1 of the lint adoption. Mechanical, behavior-preserving:
    ruff format . # 79 files: whitespace, wrapping,
    # trailing commas (quote-style=preserve
    # so quotes are NOT churned this pass)
    ruff check --fix --select I,F841 . # import sorting (I001) + the safe
    # subset of unused-variable removals
    Adds a CI gate (tests.yml) that enforces ONLY what is now 100% clean:
    `ruff format --check` + `ruff check --select I`. ruff.toml keeps the full
    target select (F401/F811/F841/I) as the goa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
    [CalibrationWizard.py, PrimingControlWidget.py, SettingsTab.py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]
2026-05-29 refactor(lint): remove unused imports (F401) + widen CI gate (3.7b-2)
    Phase 3.7b-2. Removes 118 unused imports flagged by F401. 112 were
    auto-removed by `ruff check --fix --select F401`; the 6 non-auto-fixable
    were each reviewed by hand:
    - ui/__init__.py (4): AnimalEntryWidget, ProjectsSection,
    RelayUnitWidget, RunStopSection were re-exported from the package but
    are NOT in __all__ and nothing imports them via `ui` (callers import
    straight from the submodules). Dead re-exports -> removed. The 10
    __all__ names keep their imports, so test_ui_package_imports_cleanly
    still passes.
    - flow_sensor_factory.py (2): the `from .flow_sensor import ...` /
    `from .uart_flow_sen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
    [CalibrationWizard.py, PrimingControlWidget.py, SettingsTab.py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]
2026-05-29 refactor(lint): resolve F841 unused-vars + F811 redefinitions; full CI gate (3.7b-3)
    Phase 3.7b-3 — closes the ruff adoption. Each item reviewed, not
    blanket-fixed.
    F841 unused-variable (10), handled by intent:
    - Pure dead assignments removed (RHS side-effect-free): relay_worker
    current_time, solenoid_flow_strategy cid + valve_close_time,
    schedule_wizard animal_id + is_going_forward, help_content_manager p,
    HelpTab has_any (both the init and the set).
    - CalibrationWizard: a per-quality `color` was computed in all 4 branches
    but never applied to any widget — removed as dead code; comment left
    so quality-coloring can be wired up intentionally later.
    - system_cont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
    [CalibrationWizard.py, SettingsTab.py, relay_worker.py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]
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2026-05-29 refactor(drivers): retire legacy direct-I²C flow sensor (v1.9.0)
    The SLF3S0600FDriver (direct-I²C Sensirion) was dead: nothing imported it
    except the factory's 'i2c' branch, and production runs the Teensy UART
    bridge. A future flow sensor is different hardware/components and will get
    its own driver, so the legacy concrete driver has no reuse value — keeping
    it is speculative-retention debt.
    Delete flow_sensor.py and the factory's 'i2c' path; flip the factory
    default to 'uart' (already the default in system_controller). A device with
    a stale flow_sensor_type='i2c' degrades safely to calibration-only mode
    (relay_worker catches the ValueError), not a crash. Repoint the manual
    hardware diag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
    [flow_sensor_factory.py]
2026-05-29 fix(ui): repair Delivery hardware-mode help text and polish the dropdown (v1.9.1)
    The mode-selection help label mixed <b> tags with "\n". A QLabel with any
    HTML switches to rich-text mode where "\n" is ignored, so the two bullets
    collapsed onto one run-on, awkwardly wrapped line. Use <br> and give the
    label its own full-width row so both bullets read cleanly.
    Polish the hardware-mode dropdown: display capitalized labels (Solenoid /
    Pump) while storing the canonical lowercase value as userData, so the saved
    hardware_mode setting consumed by the strategy factory and relay worker is
    unchanged. Add QComboBox popup item padding / min-height / hover styling in
    both themes — the popup had no ::i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
    [SettingsTab.py]
2026-05-29 fix(ui): lay out the hardware-mode card as a balanced two-column grid
    The selector previously sat in a form row that left a large blank area to
    its right and pushed the help text into a cramped, half-width column. Switch
    the card to a QGridLayout: the "Hardware Mode:" label and the (width-capped)
    combo stay compact on the left, and the explanatory bullets occupy the
    stretch column to their right, top-aligned — so the wide card reads as one
    balanced row with no dead space.
    [SettingsTab.py]
2026-05-29 style(ui): re-apply ruff format to SettingsTab.py hardware-mode grid
    PR #96 merged without its format commit (the fix landed on the branch after
    the merge was cut), leaving main failing the `ruff format --check` gate on
    SettingsTab.py. Re-collapse the two addWidget() calls in the hardware-mode
    grid onto single lines. Whitespace only; no behavior change. Unblocks CI for
    all subsequent PRs.
    [SettingsTab.py]
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
